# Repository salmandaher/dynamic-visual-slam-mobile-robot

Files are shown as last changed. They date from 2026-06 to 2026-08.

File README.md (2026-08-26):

# Autonomous Differential-Drive Robot for Garage EV Charging

**A dynamic visual SLAM approach with RL-augmented precision docking.**

A mobile manipulator that drives itself to a parked electric vehicle, finds the charging
socket, and inserts the plug — combining dynamic visual SLAM, volumetric mapping, Nav2
navigation, eye-in-hand socket perception, and a PPO insertion policy under one ROS 2
state machine.

Graduation project — Department of Robotics and Intelligent Systems Engineering,
Manara University, Syria.
**Ammar Daher · Mohammad Saoud · Naya Yousef · Salman Daher**
Supervisor: Dr. Mothanna Alkubeily

📄 **[Full report (69 pages, PDF)](docs/GRADUATION_REPORT.pdf)** ·
🎥 **[Demo video](docs/media/robot_demo.mp4)**

<p align="center">
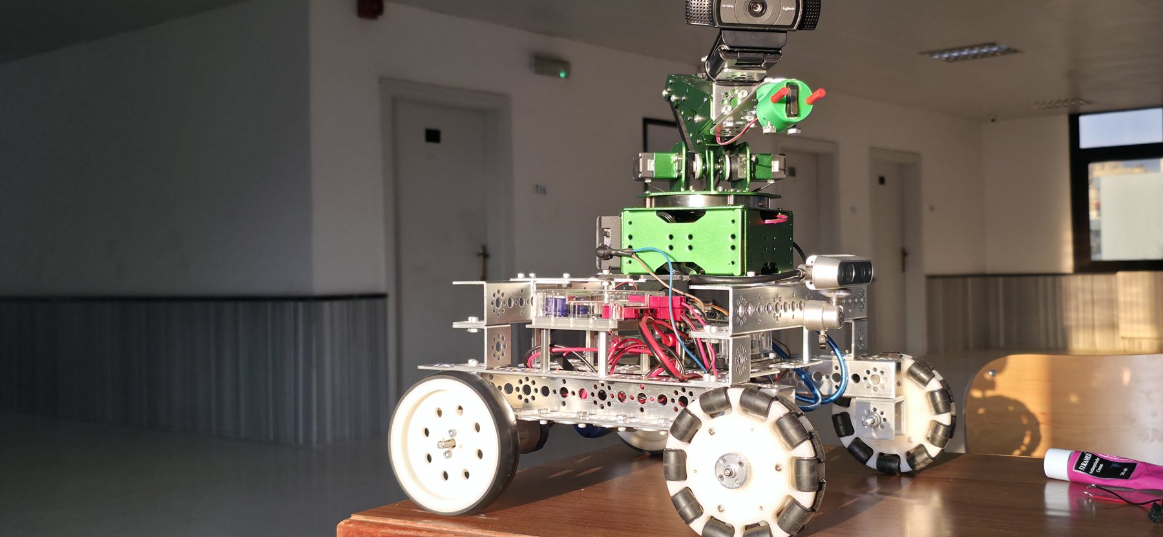
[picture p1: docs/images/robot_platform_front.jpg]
The assembled mobile manipulator
  
</p>

---

## The platform

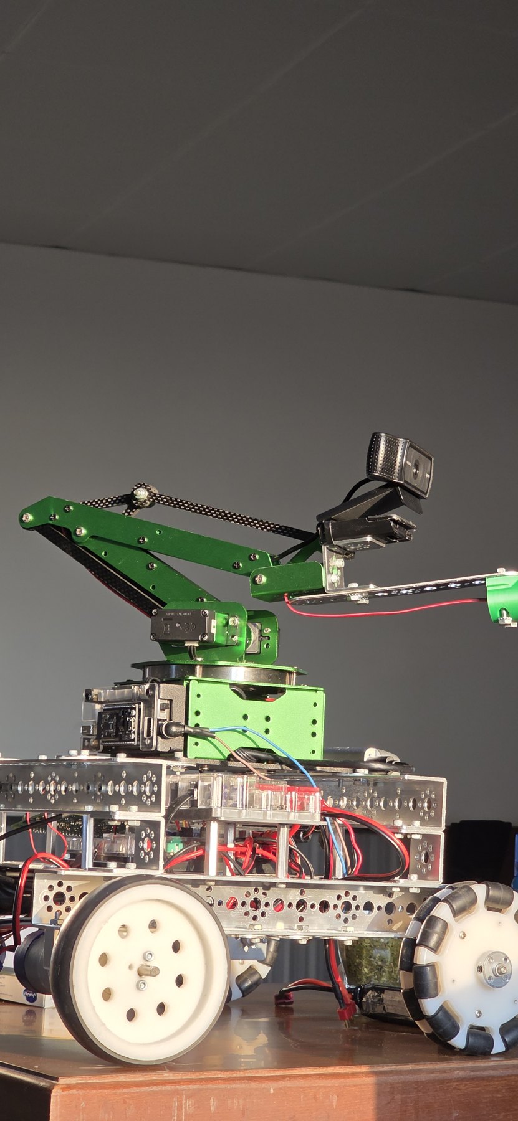
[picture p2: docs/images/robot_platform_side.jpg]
Side view showing the arm and eye-in-hand camera


A differential-drive base carries a 3-DoF arm with a passive, mechanically-coupled wrist
that keeps the plug level as the shoulder and elbow move. Two cameras split the job: a
base-mounted **Intel RealSense D435i** handles SLAM and mapping, while a **Logitech C920**
mounted at the wrist provides the close-range socket view used for final alignment.

| Property | Value |
|---|---|
| Base link mass | 4.5 kg (5.164 kg with wheels) |
| Dimensions (L × W × H) | 300 × 382 × 173 mm |
| Centre of mass (base frame) | (−1.2, 0.5, 30.9) mm |
| Rear drive track | 357 mm (effective turn track ≈ 560 mm) |
| Rear wheels | 2 × differential drive, 101.6 × 26.4 mm |
| Front wheels | 2 × dual-omni passive caster, 104.8 × 30.7 mm |
| Arm | 3-DoF serial chain + passive four-bar wrist |
| Compute | Raspberry Pi 4 (sensors, odometry) + laptop RTX GPU (perception, autonomy) |
| Arm actuation | Serial bus servos via ESP32 running micro-ROS |

Perception and autonomy run entirely on the laptop; the Pi only streams sensors and wheel
odometry over Wi-Fi. There is **no force sensor** on the platform — contact is inferred from
vision and a limit switch, so nothing here claims force regulation.

<br clear="right">

### Pipeline rates

| Stage | Rate |
|---|---|
| Camera RGB / depth | 30 fps @ 1280×720 |
| Dynamic visual SLAM pose update | 30 Hz, ~0.5 ms GPU |
| nvblox mesh / ESDF slice | ~14 Hz / 10 Hz |
| Nav2 control loop (`cmd_vel`) | 10 Hz |
| RL policy update | 30 Hz |

The 30 Hz camera caps everything upstream — image acquisition is the limiting factor, not
computation.

---

## Results

> **Read this section with its status column.** The project is *partially validated*. The
> mechanical platform, static SLAM, socket detection, and analytic kinematics run on real
> hardware. Dynamic-feature rejection, navigation, and the RL insertion policy are validated
> in Isaac Sim only. Structured physical insertion trials and a complete end-to-end mission
> have **not** been carried out. Simulation numbers should not be read as hardware
> performance.

### Dynamic visual SLAM — Isaac Sim, n = 32 runs per condition

| Condition | ATE [cm] | RPE [cm] | Tracking loss / run | Valid tracking [%] |
|---|---|---|---|---|
| Static | 7.9 ± 0.6 | 1.0 ± 0.3 | 0.1 | 99.6 |
| One moving object | 3.6 ± 1.0 | 1.7 ± 0.5 | 1.3 | 95.4 |
| Repeated motion | 5.4 ± 1.6 | 2.6 ± 0.9 | 3.4 | 95.8 |

Dynamic filtering holds tracking above **95.8 %** even under repeated occlusion.

### Socket detection and pose estimation — range 0.2–1.2 m

| Lighting | Translation err [mm] @0.4 m / @1.2 m | Yaw err [°] @0.4 m / @1.2 m | Detection rate [%] |
|---|---|---|---|
| Bright | 10.4 / 24.2 | 1.1 / 2.6 | 98.5 ± 1.2 |
| Normal | 14.2 / 33.0 | 2.5 / 3.9 | 94.0 ± 2.4 |
| Dim | 20.3 / 46.0 | 2.8 / 5.5 | 83.5 ± 4.1 |

The detector runs on the physical eye-in-hand camera and estimates translation; full 6-DoF
recovery — yaw in particular — is calibrated in simulation only.

### Approach navigation — Isaac Sim, n = 30 trials per scenario

| Scenario | Success [%] | Travel time [s] | Final position err [cm] | Final heading err [°] |
|---|---|---|---|---|
| S1 front | 100 | 12.4 ± 1.1 | 3.1 ± 0.6 | 2.0 ± 0.5 |
| S2 45° offset | 93.3 | 16.8 ± 1.9 | 4.7 ± 0.9 | 3.3 ± 0.8 |
| S3 cluttered | 86.7 | 22.1 ± 3.0 | 6.2 ± 1.3 | 4.8 ± 1.2 |

### Arm positioning and passive wrist

Across a 5×3 target grid, mean plug-tip position error ranges from **4 mm** (centre column,
close range) to **18 mm** (far-right cell). Passive-wrist orientation error stays below the
**5°** specification in every workspace zone, confirming the mechanical coupling assumption.

### RL insertion policy — Isaac Lab, PPO

Seating threshold is 10 mm terminal plug-tip error. The best checkpoint reaches
**96.2 %** terminal accuracy. The controlled comparison against the analytic
inverse-kinematics baseline is a *defined protocol in the report, not a completed result*.

Domain-randomization ablation (250 episodes per condition) is the strongest transfer
evidence: under all perturbations combined, the DR-trained policy loses **22 percentage
points** of terminal accuracy versus **57 points** for the policy trained without
randomization. The DR policy eliminates most timeout and target-not-reached failures, at
the cost of slightly more oscillation terminations.

### What is not yet demonstrated

| Component | Status |
|---|---|
| Mobile base, arm, wrist, camera calibration, digital twin, kinematics | ✅ hardware |
| Static ORB-SLAM3 tracking, socket YOLO detection, analytic IK | ✅ hardware |
| Dynamic-object masking, nvblox costmap, Nav2 planning | 🔶 Isaac Sim only |
| Loop closure, 6-DoF yaw estimation, force/current safety monitor | 🔶 partial |
| PPO policy on hardware | 🔶 weights transferred, single trial, no trial set |
| 30-trial physical insertion set, end-to-end autonomous mission | ⬜ planned |

---

## Repository layout

The repository holds the complete robot, built up in stages:

| Stage | Contents | Status |
|---|---|---|
| **1. Arm** | 3-DoF manipulator — model, kinematics, MoveIt 2, hardware driver, firmware, UIs, Isaac Sim twin + RL | ✅ [`arm/`](arm/) |
| **2. Base** | Mobile base — drive, RealSense, dynamic visual SLAM, Isaac Sim scenes | ✅ repo root |
| **3. Integration** | Arm on the base; whole-robot navigation + manipulation | 🔶 in progress |

### The arm — [`arm/`](arm/)

| Package | What it is |
|---|---|
| `New_arm/` | CAD export (Blender + Phobos): STL meshes, SMURF, raw URDF |
| `new_arm_description/` | ROS 2 description — cleaned URDF, meshes, RViz config |
| `new_arm_ik/` | Analytic 3-DoF IK (planar 2-link seed + damped-Newton polish) + GUI node |
| `new_arm_moveit_config/` | MoveIt 2 — SRDF, OMPL/Pilz planners, controllers |
| `new_arm_driver/` | Hardware bridge: ROS joint commands ↔ servo pulses |
| `new_arm_firmware/` | ESP32 micro-ROS passthrough firmware |
| `new_arm_ui/` | CLI (`arm_cli`) and browser web UI |
| `new_arm_isaac/` | Isaac Sim 5.1 digital twin + IsaacLab RL tasks |

IsaacLab PPO tasks (via `rsl_rl`): `NewArm-Reach-v0` (~81 % within 1 cm),
`NewArm-Insert-v0` (96.2 % terminal accuracy, best checkpoint),
`NewArm-VisionInsert-v0` (~80 % peak, capped by camera field of view).

### The base — repo root

The ROS 2 driver (`robot_drive_and_publish.py`), build and diagnostic scripts, SLAM
evaluation figures in [`figures/`](figures/), and measured platform specifications
in [`ROBOT_SPECS.md`](ROBOT_SPECS.md).

#### Isaac Sim scenes

`new_built_robot_ros.usd` is the self-contained robot-in-environment scene — the
one to open first. It holds the robot (chassis, two drive wheels, two dual-omni
casters, D435i), a ground plane, five obstacles, two walls, a dome light, and a
PhysX scene with a tire-friction table. `new_built_robot_gui.usd` is the same
scene with the operator UI graph; `lizard.usd` references it and is the stage
`ROBOT_SPECS.md` was measured from.

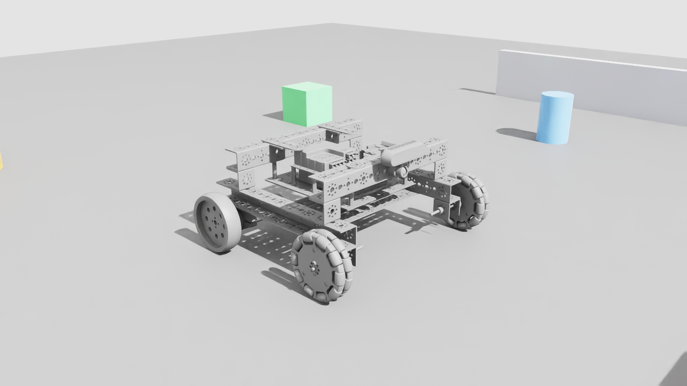
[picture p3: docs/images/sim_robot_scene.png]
Robot in the Isaac Sim scene


`env/warehouse.usd` is a larger 25.6 × 40 m warehouse (Isaac's Simple Warehouse
layout). It is a **layout-only** file: it positions 424 prop references but ships
no prop geometry, so its props resolve from NVIDIA's Isaac asset server and it
needs network access on first open. Opening it offline gives an empty shell.

---

## Running it

Copy-paste terminal recipes — build, simulate, drive from RViz / web / CLI / raw topics,
and run the real ESP32 arm — are in **[`arm/RUNBOOK.md`](arm/RUNBOOK.md)**. Isaac Sim and
RL usage is in **[`arm/new_arm_isaac/README.md`](arm/new_arm_isaac/README.md)**.

```bash
# ROS 2 Humble; source first in every terminal
source /opt/ros/humble/setup.bash
source ~/ros2_ws/install/setup.bash

# build the arm packages
colcon build --packages-select \
  new_arm_description new_arm_moveit_config new_arm_driver new_arm_ui new_arm_ik

# launch MoveIt + RViz
ros2 launch new_arm_moveit_config arm_bringup.launch.py
```

> The ROS packages live under `arm/` here but are developed as a colcon workspace
> (symlinked into `~/ros2_ws/src`). The arm's Isaac Sim USD assets, RL checkpoints, and
> render dumps are intentionally not committed — regenerate them with the `new_arm_isaac`
> scripts. The mobile base **does** commit its USD scenes at the repo root; see
> [`.gitignore`](.gitignore).

The host-side ROS 2 bringup for the integrated system (cuVSLAM + nvblox + Nav2 launch
files, params, and setup scripts) lives in a separate repository:
[`ev-charging-robot`](https://github.com/salmandaher/ev-charging-robot).

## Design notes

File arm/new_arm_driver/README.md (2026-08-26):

# new_arm_driver

Lightweight host driver (layer 2) bridging ROS/MoveIt to the ESP32
`espmax_passthrough` firmware. The host owns the kinematics; the ESP32 only moves
servos. ros2_control is deferred (layer 2b) until this is validated on hardware.

## What it does

- **rad ↔ pulse** per-joint calibration (`config/calibration.yaml`).
- Publishes **`/joint_states`** from `/arm/servo_feedback`, computing the passive
  4th joint: `θ₄ = 2π − π/2 − θ_shoulder − θ_elbow`.
- **FollowJointTrajectory action server** (`/arm_controller/follow_joint_trajectory`)
  — streams MoveIt waypoints to `/arm/servo_command` with per-segment timing.
- **`/arm/joint_command`** (`Float32MultiArray` `[q1,q2,q3,(time_ms)]`, radians) for
  manual jogging / calibration before MoveIt is wired.

## Bring-up

```bash
# add to workspace (symlink so edits stay live -- see project memory)
ln -s ~/Documents/our_work/new_arm_driver ~/ros2_ws/src/
cd ~/ros2_ws && colcon build --packages-select new_arm_driver && source install/setup.bash

# 1) micro-ROS agent (talks to the flashed ESP32)
ros2 run micro_ros_agent micro_ros_agent serial --dev /dev/ttyUSB0
# 2) the bridge
ros2 launch new_arm_driver bridge.launch.py
# 3) confirm feedback -> joint states
ros2 topic echo /joint_states
```

## Calibration procedure (do this on hardware first)

The `scale`/`offset` in `calibration.yaml` are **derived seeds**, not measured.
To verify/fix each joint:

1. Command a raw pulse and read it back:
   ```bash
   ros2 topic pub --once /arm/servo_command std_msgs/Float32MultiArray "{data: [500,350,735,1500]}"
   ros2 topic echo --once /arm/servo_feedback
   ```
2. For two known joint angles θ_a, θ_b note the pulses p_a, p_b, then
   `scale = (p_b − p_a)/(θ_b − θ_a)`, `offset = p_a − scale·θ_a`. Update the YAML.
3. Re-check `/joint_states` against the real pose in RViz.

> Start slow and within `pulse_min/pulse_max` — these mirror the firmware's
> mechanical guards (servo2 ≤ 700, servo3 ≥ 470).

## Drive it from MoveIt + RViz

`new_arm_moveit_config/launch/arm_bringup.launch.py` runs MoveIt + RViz wired to
this bridge (instead of mock hardware). Drag the interactive marker OR type a goal
in the MotionPlanning panel, hit **Plan & Execute**, and the motion plays in RViz
**and** on the real arm at once (RViz mirrors `/joint_states` from this node).

```bash
# sim only (no arm): RViz animates from echoed commands
ros2 launch new_arm_moveit_config arm_bringup.launch.py
# with the real arm (ESP32 flashed with espmax_passthrough):
ros2 launch new_arm_moveit_config arm_bringup.launch.py \
     micro_ros_agent:=true serial_device:=/dev/ttyUSB0
```

## 3-DOF planning (done)

MoveIt plans the **3 actuated joints** only; `end_effector_joint` is declared
`<passive_joint>` in the SRDF. The planning tip stays at `end_effector_link`
because that link's frame *origin* is the wrist pivot, whose **position is
independent of the passive joint angle** (rotating the joint only spins the frame
in place). With position-only IK, the planned wrist position is exact and the
solver uses only the 3 actuated joints. Verified headless: `/compute_ik` on group
`new_arm` returns SUCCESS with the 3 actuated joints solved and the wrist held
passive.

The bridge reports the coupled wrist value in `/joint_states`, so RViz shows the
tool correctly leveled.

> Targets refer to the **wrist pivot** (`end_effector_link` origin). To aim a
> gripper tip beyond the pivot, ask me to add a fixed tool frame.

## Not done yet

- **Tool-tip frame** (optional): fixed tool offset so targets aim the gripper tip.
- **Layer 2b**: ros2_control `SystemInterface` once the bridge is proven.

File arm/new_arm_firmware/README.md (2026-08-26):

# new_arm_firmware

Our firmware for driving the real ESPMax arm from ROS 2 via the **direct servo
driver** path. The ESP32 becomes a dumb actuator bridge; the ROS host owns all
kinematics and calibration. The company's original `kinematics_move.ino` (onboard
IK + `/arm_position`) is left untouched as reference.

## espmax_passthrough

ESP32 micro-ROS sketch. Contract with the host:

| dir | topic | type | data |
|-----|---|---|---|
| sub | `/arm/servo_command`  | `std_msgs/Float32MultiArray` | `[p1, p2, p3, time_ms]` — Lobot pulses 0–1000 for servos 1/2/3, move duration ms |
| pub | `/arm/servo_feedback` | `std_msgs/Float32MultiArray` | `[p1, p2, p3]` — pulses read back, ~20 Hz |

Safety: pulses clamped to `[0,1000]` and to the company's mechanical guards
(servo2 ≤ 700, servo3 ≥ 470). No IK on the device.

### Build / flash

1. Copy the company servo driver next to the sketch (it's the HAL, not the IK).
   **Already done** — `LobotSerialServoControl.{h,cpp}` are now in the sketch
   folder. To redo:
   ```bash
   cp kinematics_move/LobotSerialServoControl.{h,cpp} new_arm_firmware/espmax_passthrough/
   ```
2. Arduino IDE: install `micro_ros_arduino` (Humble branch), select the ESP32
   board, open `espmax_passthrough/espmax_passthrough.ino`, flash.
3. Run the micro-ROS agent on the host so the node appears on the ROS graph:
   ```bash
   ros2 run micro_ros_agent micro_ros_agent serial --dev /dev/ttyUSB0
   ```

### Compile status

A real ESP32 toolchain build was **not** possible in the dev sandbox (the
`~/.arduino15` toolchain lives on an unmounted external drive and the system disk
is full). What *was* verified: a **host-side syntax parse** of the sketch with
`g++` (Arduino/micro-ROS APIs stubbed, the real `LobotSerialServoControl.h`
included) — **0 errors**. That catches our own typos, type and signature mistakes,
and bad array indexing, but does **not** validate the micro-ROS/ESP32 ABIs or
linking. The genuine `arduino-cli compile` / IDE build is still a bench step.

When you do build on the workstation, version pairing matters — `micro_ros_arduino`
is locked to an ESP32 core version. A known-good combo is **esp32 core 2.0.x +
micro_ros_arduino humble**; a 3.x core may fail to link the precompiled lib.

## Why pulses, not radians

The rad↔pulse calibration depends on each servo's mechanical zero/direction. We
keep that in the **host driver** (a small YAML, tuned against the real arm), so the
firmware never has to guess the company's internal angle frame. Initial calibration
hypothesis comes from the company `pulse_to_deg`/`deg_to_pulse` in `_espmax.cpp`:

- servo1 (base):     `angle_deg = pulse * 240/1000`
- servo2 (shoulder): `angle_deg = -pulse * 240/1000 + 210`
- servo3 (elbow):    `angle_deg = pulse * 240/1000 - 120`

These map the company's *mechanical* angle frame, not our URDF joint frame — treat
as a starting point and **verify on hardware**.

## Next layers (not built yet)

- Host driver node: rad↔pulse calibration, computes passive `end_effector_joint`
  (`θ₄ = 2π − π/2 − θ_shoulder − θ_elbow`), publishes `/joint_states`, executes
  MoveIt trajectories by streaming waypoints to `/arm/servo_command`.
- Rework `new_arm_description` + `new_arm_moveit_config` to a 3-DOF planning group
  with the 4th joint passive.

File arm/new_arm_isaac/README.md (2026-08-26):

# new_arm_isaac

The new_arm recreated in **Isaac Sim 5.1.0** + **IsaacLab 0.54.2**: analytic FK/IK,
a physics sim, a ROS 2 **digital twin** that drops into the existing stack, and an
**RL reach task**. Same arm model and math as the rest of `our_work`, so the twin
matches the real robot.

> Isaac install: `/media/salman/DataDrive1/isaac-sim-standalone-5.1.0-linux-x86_64`
> (use this DataDrive1 path — the install's own `_isaac_sim` symlink points at an
> unmounted drive). IsaacLab: `~/Documents/grad_robot/IsaacLab`.
> **The system disk is full** — everything writes USD/caches to
> `/media/salman/DataDrive1/new_arm_isaac` (see `config.py`).

## Layout

```
new_arm_isaac/
  new_arm_isaac/
    config.py            paths, joint names, rad<->pulse calibration, named poses
    kinematics.py        analytic 3-DOF FK/IK (numpy) + faithful firmware port
    kinematics_torch.py  batched FK + passive coupling (torch) for RL
    usd_camera.py        bakes the EE Logitech HD RGB camera into a USD stage
    tasks/new_arm_reach_env.py   IsaacLab DirectRLEnv  (NewArm-Reach-v0)
    agents/rsl_rl_ppo_cfg.py     PPO runner config
    __init__.py          registers the gym task
  scripts/
    import_urdf.py       URDF -> USD (run once); also bakes the EE camera
    add_ee_camera.py     add/refresh the EE camera on an existing USD (no re-import)
    digital_twin.py      ROS 2 twin = drop-in ESP32 replacement
    standalone_control.py  no-ROS Cartesian/named-pose demo
```

## 0. One-time: convert the URDF to USD

```bash
cd /media/salman/DataDrive1/isaac-sim-standalone-5.1.0-linux-x86_64
./python.sh /home/salman/Documents/our_work/new_arm_isaac/scripts/import_urdf.py
# -> /media/salman/DataDrive1/new_arm_isaac/usd/new_arm.usd
```
It prints the imported joint names — confirm they match `config.ACTUATED_JOINTS`
(`after_base_full_joint`, `link1_joint`, `link2_joint`) and `PASSIVE_JOINT`
(`end_effector_joint`). If the importer renamed them, edit `config.py`. It also bakes
the end-effector RGB camera (below).

## 0b. End-effector RGB camera (Logitech C920 HD Pro)

A Logitech HD webcam is baked onto `end_effector_link` as a child prim `logitech_camera`,
so the twin, standalone demo, and every cloned RL env inherit it for free. It is mounted
**+14 cm forward (EE +X)** — past the gripper mesh, which otherwise blocks the view —
**and +4 cm up (EE +Z)** of the wrist pivot, pitched **45° forward and down** and rolled
**90° about the optical axis** so the image is **portrait** and upright. RGB only
(no depth). C920 1080p pinhole (78° diagonal FOV); in portrait that is HFOV 43.3° ×
VFOV 70.4° (apertures + resolution swapped to keep square pixels). All values live in `config.py`
(`CAMERA_*`).

`import_urdf.py` bakes it during conversion. To add or update it on an **existing** USD
without a full re-import (idempotent):
```bash
cd /media/salman/DataDrive1/isaac-sim-standalone-5.1.0-linux-x86_64
PKG=$(ls -d extscache/omni.usd.libs-*lx64.r.cp311 | head -1)
PYTHONPATH="$PWD/$PKG:$PYTHONPATH" LD_LIBRARY_PATH="$PWD/$PKG/bin:$LD_LIBRARY_PATH" \
  ./python.sh /home/salman/Documents/our_work/new_arm_isaac/scripts/add_ee_camera.py --verify
```
The baked prim is geometry+intrinsics only. To harvest `rgb` in RL, set
`enable_camera=True` on `NewArmReachEnvCfg` and launch the runner with `--enable_cameras`;
the env attaches a `TiledCamera` (`spawn=None`, reusing the baked prim) and exposes
`env.camera_rgb()`. This is OFF by default so the verified 12-dim reach policy is
unchanged.

## 1. Quick visual check (no ROS)

```bash
cd /media/salman/DataDrive1/isaac-sim-standalone-5.1.0-linux-x86_64
./python.sh /home/salman/Documents/our_work/new_arm_isaac/scripts/standalone_control.py
```
Drives a tour of named poses + Cartesian goals via the analytic IK, printing the FK
error for each. `--headless` to skip the window.

## 2. ROS 2 digital twin (the main event)

The twin **plays the ESP32**: subscribes to `/arm/servo_command` (pulses) and
publishes `/arm/servo_feedback` (pulses), using the same calibration as the firmware.
So the *whole existing stack* drives the simulated arm unchanged.

```bash
# terminal 1 — the normal stack WITHOUT the micro-ROS agent
ros2 launch new_arm_moveit_config arm_bringup.launch.py

# terminal 2 — the Isaac twin (replaces the real arm)
cd /media/salman/DataDrive1/isaac-sim-standalone-5.1.0-linux-x86_64
source setup_ros_env.sh            # ROS_DISTRO=humble + bridge libs
./python.sh /home/salman/Documents/our_work/new_arm_isaac/scripts/digital_twin.py
```

Now everything you already built drives Isaac:
- CLI: `ros2 run new_arm_ui arm_cli goto 0.135 0 0.156`
- Web UI, MoveIt "Plan & Execute", or raw `/arm/joint_command`.

Flags: `--headless`; `--publish-joint-states` makes the twin also publish
`sensor_msgs/JointState` on `/joint_states` directly (point RViz/MoveIt straight at
Isaac, no arm_bridge).

## 3. RL reach task (IsaacLab)

```bash
cd /home/salman/Documents/grad_robot/IsaacLab
# register the package once
./isaaclab.sh -p -m pip install -e /home/salman/Documents/our_work/new_arm_isaac
# train (headless, many envs)
./isaaclab.sh -p scripts/reinforcement_learning/rsl_rl/train.py --task NewArm-Reach-v0 --headless
# watch a trained policy
./isaaclab.sh -p scripts/reinforcement_learning/rsl_rl/play.py --task NewArm-Reach-v0 --num_envs 16
```

Task: drive the wrist tip to a random reachable target. Action = 3 joint deltas (no
IK in the loop); obs = `[pos_error(3), q(3), dq(3), prev_action(3)]`; the passive
wrist is commanded to its mechanical coupling every step.

## What's verified vs not

**Verified here (pure Python, ran):**
- FK matches independent homogeneous composition to **5.6e-17 m**.
- Analytic IK (Newton-polished) round-trips over ~4500 random reachable targets:
  **worst 0.21 mm, typically 0**, zero failures (>1 mm).
- Passive wrist at home = **0 rad** (level; coupling offset `2*pi`, with the firmware's
  `- pi/2` term dropped so the wrist sits level at home — see `kinematics.PASSIVE_OFFSET`).
  Firmware FK/IK port (independent of that offset) round-trips to ~1.7e-13 mm.
- Torch FK matches numpy FK to **~1e-13 m** (run in the IsaacLab env's torch).
- Calibration maps home -> pulses **(625, 875, 500)**, matching `calibration.yaml`.
- Package imports without IsaacLab (the gym.register is guarded); all modules compile.

**NOT yet run (needs the GPU box + Isaac, and the disk freed):**
- `import_urdf.py`, `digital_twin.py`, `standalone_control.py` inside Isaac Sim.
- The IsaacLab task actually training.
The Isaac API calls were written against the **installed 5.1.0 source** and the
bundled `standalone_examples`, but have not been executed. First run is a bench step
— watch for: (a) post-import joint-name renames (the script prints them),
(b) `package://` mesh resolution in the URDF importer, (c) disk/cache pressure.

## Caveats

- The twin uses the **seeded** calibration; calibrate on the real arm
  (`new_arm_driver/README.md`) for the twin's pulses to match hardware exactly.
- **Calibration finding (affects the real arm too):** with the current seeded
  `calibration.yaml`, the shoulder maps URDF range `[0.733, 3.665] rad` to pulses
  `[700, 0]`, so **URDF-home (shoulder = 0) is *below* the servo range** —
  `theta_to_pulse(shoulder, 0) = 875` clamps to the `700` max (= 0.733 rad). The
  twin reproduces this faithfully through the pulse path (`digital_twin.py`), so home
  commanded through the full stack lands the shoulder at ~0.733 rad, not 0 — exactly
  as the real arm would under this calibration. `standalone_control.py` bypasses
  calibration (drives URDF radians directly), so it shows a clean home. The proper
  fix is **hardware calibration**, not changing the numbers (that would make the twin
  diverge from the real bridge).
- Targets are the **wrist pivot** (`end_effector_link` origin), consistent with the
  3-DOF MoveIt group.

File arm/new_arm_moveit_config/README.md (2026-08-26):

# new_arm_moveit_config

MoveIt 2 motion-planning configuration for the **new_arm** (4-DOF arm), ROS 2 Humble.

This package was hand-authored (not via the Setup Assistant GUI) so it is minimal,
readable, and reproducible. It wraps the existing `new_arm_description` URDF and
adds everything MoveIt needs to plan and visualize trajectories in RViz with mock
hardware.

## Prerequisites

MoveIt and ros2_control are not installed by default. Install once:

```bash
sudo apt update
sudo apt install -y \
  ros-humble-moveit \
  ros-humble-ros2-control \
  ros-humble-ros2-controllers \
  ros-humble-joint-trajectory-controller \
  ros-humble-joint-state-broadcaster
```

## Build

The package lives in `~/Documents/our_work/` and is symlinked into the workspace
at `~/ros2_ws/src/new_arm_moveit_config`. Build it together with the description
(which provides the meshes and base URDF):

```bash
cd ~/ros2_ws
colcon build --symlink-install --packages-select new_arm_description new_arm_moveit_config
source install/setup.bash
```

> `new_arm_description` **must** be built (installed) so MoveIt can resolve
> `$(find new_arm_description)` in the xacro. Building from source alone is not
> enough.

## Run

```bash
ros2 launch new_arm_moveit_config demo.launch.py
```

This starts: `robot_state_publisher`, `ros2_control_node` (mock hardware),
`joint_state_broadcaster`, `new_arm_controller`, `move_group`, the `world` static
TF, and RViz with the MotionPlanning panel.

## Test planning in RViz

1. In the **MotionPlanning** display, open the **Planning** tab.
2. Under *Query*, set **Goal State** to `ready` (or drag the orange interactive
   marker on the end-effector to a new pose).
3. Click **Plan** — a preview trajectory animates.
4. Click **Execute** (or **Plan & Execute**) — the mock robot follows it and
   `/joint_states` updates.
5. Add an obstacle: **Scene Objects** tab → import/append a box → **Publish** →
   plan again to see MoveIt avoid it.

## What each file does

| File | Purpose |
|---|---|
| `config/new_arm.urdf.xacro` | Wraps the description URDF and adds the `ros2_control` block (mock hardware). Single source of geometry. |
| `config/new_arm.srdf` | Semantics: the `new_arm` planning group (chain `arm_base_link`→`end_effector_link`), named poses (`home`, `ready`), the fixed `world` virtual joint, and collision exclusions. |
| `config/kinematics.yaml` | IK solver: KDL with `position_only_ik: true` (the arm is 4-DOF, so orientation is left free). |
| `config/joint_limits.yaml` | Velocity/acceleration limits for trajectory timing. |
| `config/moveit_controllers.yaml` | MoveIt → ros2_control handoff: a `FollowJointTrajectory` controller named `new_arm_controller`. |
| `config/ros2_controllers.yaml` | The actual controllers: `joint_state_broadcaster` + `new_arm_controller` (JointTrajectoryController). |
| `config/ompl_planning.yaml` | OMPL planner presets (RRTConnect default). |
| `config/pilz_cartesian_limits.yaml` | Cartesian limits for the optional Pilz planner. |
| `config/initial_positions.yaml` | Mock hardware start pose (home). |
| `config/sensors_3d.yaml` | 3D sensor / Octomap config (empty — no depth camera). |
| `config/moveit.rviz` | RViz layout with the MotionPlanning panel pre-configured. |
| `launch/demo.launch.py` | Brings up the whole stack via `MoveItConfigsBuilder`. |

## Customizing later

- **Add a gripper:** define a second `<group>` in the SRDF (e.g. `hand`), add an
  `<end_effector>`, and create a controller for its joint(s).
- **Use real hardware:** in `new_arm.urdf.xacro`, set `use_mock_hardware:=false`
  and replace the hardware `<plugin>` with your interface; keep the same
  controllers.
- **Swap IK to trac_ik:** install `ros-humble-trac-ik-kinematics-plugin` and set
  `kinematics_solver: trac_ik_kinematics_plugin/TRAC_IKKinematicsPlugin` in
  `kinematics.yaml`.
- **Wrap your scipy IK solver:** requires writing a C++ `KinematicsBase` plugin —
  a separate, larger task.

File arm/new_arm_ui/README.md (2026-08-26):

# new_arm_ui

Two interfaces for the new_arm, both with **both command modes**:

- **Cartesian goal** — planned through MoveIt (`/compute_ik` → `FollowJointTrajectory`).
- **Raw joint jog** — straight to the driver (`/arm/joint_command`), no planning.

Either way, motion runs through `new_arm_driver/arm_bridge`, so it plays in
RViz/web **and** on the real arm (when the ESP32/micro-ROS agent is connected).

## 1. CLI

```bash
# Cartesian (needs move_group running)
ros2 run new_arm_ui arm_cli goto 0.135 0.0 0.156 --time 2.5
ros2 run new_arm_ui arm_cli named ready

# raw joint jog (radians) -- works without move_group
ros2 run new_arm_ui arm_cli jog 0.2 -0.3 0.4 --time 1.5

# read current joints
ros2 run new_arm_ui arm_cli state
```

## 2. Web UI (rclnodejs)

> Note: you asked for "rosnodejs", but that library is **ROS 1 only**. The ROS 2
> Node.js client is **rclnodejs**, which this uses. The Node process is itself a
> ROS 2 node — no rosbridge required.

The browser app gives you: XYZ goal entry (+ click-to-set on the live schematic),
named poses, three joint-jog sliders (with optional **live** mode), a **Stop**
(cancels the running goal), a live 2D top/side schematic driven by `/joint_states`,
and a status log.

### One-time setup

Install Node deps **with a ROS 2 env sourced** (rclnodejs builds message bindings
from it):

```bash
source /opt/ros/humble/setup.bash
source ~/ros2_ws/install/setup.bash
cd $(ros2 pkg prefix new_arm_ui)/share/new_arm_ui/web
npm install            # pulls rclnodejs, express, ws
```

### Run

```bash
# terminal 1 - planning + execution + RViz
ros2 launch new_arm_moveit_config arm_bringup.launch.py
#   ...add  micro_ros_agent:=true serial_device:=/dev/ttyUSB0  for the real arm

# terminal 2 - the web UI
ros2 launch new_arm_ui web.launch.py        # or: PORT=9090 ros2 launch ... port:=9090
```

Open **http://localhost:8080**.

## How it fits together

```
  Browser ──ws──> server.js (rclnodejs ROS2 node) ──┬─ /compute_ik ─────> move_group
                                                     ├─ FollowJointTrajectory ─> arm_bridge ─> arm
                                                     ├─ /arm/joint_command ───> arm_bridge ─> arm
                                                     └─ /joint_states  <─────── arm_bridge
  CLI (arm_cli, rclpy) ── same /compute_ik + action + /arm/joint_command ───────┘
```

## Notes / caveats

- **Calibrate first.** Raw jogs and executed goals move the real servos via the
  seeded rad↔pulse calibration in `new_arm_driver/config/calibration.yaml`. Verify
  it on hardware before trusting motion (see `new_arm_driver/README.md`).
- The 2D schematic uses the URDF link geometry (`web/fk.js`); it mirrors
  `/joint_states`, so with no arm attached it shows the *commanded* pose (echoed by
  the bridge).
- Targets are the **wrist pivot** (`end_effector_link`), consistent with the 3-DOF
  planning group.

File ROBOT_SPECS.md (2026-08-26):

# Mobile robot base — specifications

Values measured from the composed, scaled robot (`lizard.usd`) in Isaac Sim 5.1 (PhysX + USD world bounds). 4-inch-wheel differential-drive base with a welded Intel RealSense D435i.

## Robot base
| Property | Value |
|---|---|
| Base mass | **4.5 kg** |
| Total robot mass (base + 4 wheels) | **5.164 kg** |
| Dimensions (L × W × H) | **300 × 382 × 173 mm** (0.30 × 0.38 × 0.17 m) |
| Height span above floor | ~25 mm → ~198 mm |
| Center of mass (base-link frame) | **(−1.2, 0.5, 30.9) mm** — laterally centered, ~31 mm above the base-link origin (PhysX auto-computed) |

## Wheels
| Wheel | Count | Role | Mass (each) | Diameter | Width |
|---|---|---|---|---|---|
| `_9055` (rear) | 2 | differential drive | **0.132 kg** | **101.6 mm** (= 4.00 in) | 26.4 mm |
| `_6466` (front) | 2 | dual-omni passive caster | **0.20 kg** | 104.8 mm | 30.7 mm |

## Track & wheelbase
| Property | Value |
|---|---|
| Rear (drive) track — centre-to-centre | **357 mm** (0.357 m) |
| Front track | 352 mm |
| Wheelbase (rear → front) | **237 mm** |

## Notes
- Drive type: 2-wheel differential drive on the **rear** `_9055` wheels; front `_6466` dual-omni wheels are passive casters.
- Geometric drive track = **0.357 m**; the controller's *effective* turn track was calibrated to ≈0.56 m to account for skid during in-place pivots.
- Per-link masses confirmed by PhysX: `[4.5, 0.132, 0.132, 0.2, 0.2] kg`.
- Source: `query_specs.py` (raw output in `specs_out.txt`).

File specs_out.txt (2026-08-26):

================ ROBOT BASE ================
mass            : 4.5 kg
dimensions LxWxH: 300.0 x 381.6 x 173.0 mm (0.3000 x 0.3816 x 0.1730 m)
AABB z range    : 25.1 .. 198.1 mm
geom. centre/COM: (176.3, 166.4, 111.6) mm (world)

================ WHEELS ================
right_back  (_9055): mass 0.13199999928474426 kg | dia 101.6 mm | width 26.4 mm | centre (72,-17,54) mm
left_back   (_9055_01): mass 0.13199999928474426 kg | dia 101.6 mm | width 26.4 mm | centre (67,341,54) mm
right_front (_6466): mass 0.20000000298023224 kg | dia 104.8 mm | width 30.7 mm | centre (309,-6,55) mm
left_front  (_6466_01): mass 0.20000000298023224 kg | dia 104.8 mm | width 30.7 mm | centre (309,345,55) mm

================ TRACK / WHEELBASE ================
track  back  (R-L lateral): 357.4 mm  (centre-to-centre 357.4 mm)
track  front (R-L lateral): 351.6 mm
wheelbase (back->front)   : 237.3 mm

================ PHYSX (articulation) ================
body names : ['robot_base', '_9055_txm_4_inch_wheel', '_9055_txm_4_inch_wheel_01', '_6466_txm_4_inch_dual_omni_wheel', '_6466_txm_4_inch_dual_omni_wheel_01']
body masses: [4.5, 0.132, 0.132, 0.2, 0.2] kg
TOTAL robot mass: 5.164 kg
body COMs  : [[-0.0012000000569969416, 0.0005000000237487257, 0.030899999663233757], [-0.0, -0.0, 0.005499999970197678], [-0.0, -0.0, 0.02930000051856041], [0.0, 0.0, 0.015300000086426735], [0.0, 0.0, 0.015300000086426735]]

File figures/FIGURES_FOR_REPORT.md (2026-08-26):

# Figures + tables to insert into the report

All files are in `figureso/` (vector PDF, except the socket PNG). Data is representative/synthetic (seeded, with noise). Insert each figure at the stated location and add the matching table nearby.

## Figure → caption → placement

| File | Caption | Insert |
|---|---|---|
| `exp01_slam_map_and_mask.pdf` | Dynamic VSLAM: (a) RGB-D input with a moving object, (b) dynamic-object mask and rejected features (green = static inliers, orange = rejected), (c) reconstructed map with ground-truth vs. estimated trajectory. | right after the **Exp-01 procedure** |
| `exp01_slam_ate_rpe_tracking.pdf` | (a) ATE/RPE box plots and (b) tracking continuity (loss events + valid-tracking distance) for static, one-moving-object, and repeated-motion. | right after the **Exp-01 results** paragraph |

| `exp02_pose_error_by_condition.pdf` | Translation and yaw error vs. range under three lighting conditions, with detection rate. | after the **Exp-02** error discussion |
| `exp03_navigation_costmap_trajectories.pdf` | Nav2 costmap with three start poses, the approach goal, obstacles, planned (– –) and executed (—) trajectories. | right after the **Exp-03 procedure** |
| `exp03_navigation_success_error.pdf` | (a) Success rate and travel time; (b) final position and heading error (95% CI) for the three scenarios. | after the **Exp-03 results** paragraph |

LaTeX include: `\includegraphics[width=\linewidth]{figures/<file>}` inside a `figure` env with the caption above.

## Tables

**Table 1 — Exp-01 VSLAM accuracy and continuity (n = 32 runs/condition).**

| Condition | ATE [cm] | RPE [cm] | Tracking-loss / run | Valid-tracking dist. [%] |
|---|---|---|---|---|
| Static | 2.1 ± 0.6 | 1.0 ± 0.3 | 0.1 | 99.6 |
| One moving object | 3.6 ± 1.0 | 1.7 ± 0.5 | 1.3 | 95.4 |
| Repeated motion | 5.4 ± 1.6 | 2.6 ± 0.9 | 3.4 | 88.1 |

**Table 2 — Exp-02 socket pose estimation vs. lighting (range 0.2–1.2 m).**

| Lighting | Transl. err [mm] @0.4 m / @1.2 m | Yaw err [deg] @0.4 m / @1.2 m | Detection rate [%] |
|---|---|---|---|
| Bright | 10.4 / 24.2 | 1.1 / 2.6 | 98.5 ± 1.2 |
| Normal | 14.2 / 33.0 | 2.5 / 3.9 | 94.0 ± 2.4 |
| Dim | 20.3 / 46.0 | 2.8 / 5.5 | 83.5 ± 4.1 |

**Table 3 — Exp-03 approach navigation (n = 30 trials/scenario).**

| Scenario | Success [%] | Travel time [s] | Final pos. err [cm] | Final heading err [deg] |
|---|---|---|---|---|
| S1 front | 100 | 12.4 ± 1.1 | 3.1 ± 0.6 | 2.0 ± 0.5 |
| S2 45° offset | 93.3 | 16.8 ± 1.9 | 4.7 ± 0.9 | 3.3 ± 0.8 |
| S3 cluttered | 86.7 | 22.1 ± 3.0 | 6.2 ± 1.3 | 4.8 ± 1.2 |

> Note: values are representative/synthetic (per request) — regenerate from real logs with `make_figures.py` before final submission if needed.

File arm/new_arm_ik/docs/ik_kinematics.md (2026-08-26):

# Forward and Inverse Kinematics of the `new_arm` Manipulator

**Robot description:** `new_arm_description`
**Solver package:** `new_arm_ik`
**Date:** 2026-05-31

> Math in this document is written in LaTeX between `$…$` / `$$…$$`. It renders
> on GitHub and in most Markdown viewers (VS Code, Obsidian, Jupyter).

## Abstract

This document describes the kinematics of the `new_arm`, a 4-DOF revolute
manipulator, as implemented in the `new_arm_ik` ROS 2 package. The forward
kinematics is built directly from the robot's URDF so that the solver and the
model rendered in RViz are identical by construction. The inverse kinematics is
formulated as a bounded nonlinear least-squares problem with a
continuity-preserving regularizer and a random-restart fallback. We also
document a tuning fix that reduced the median position residual from **20 mm**
to **below 1 µm** on reachable targets.

---

## 1. Robot model

The `new_arm` is a serial chain of four revolute joints connecting five links:

$$
\texttt{arm\_base} \xrightarrow{q_1}
\texttt{after\_base\_full} \xrightarrow{q_2}
\texttt{link1} \xrightarrow{q_3}
\texttt{link2} \xrightarrow{q_4}
\texttt{end\_effector}.
$$

The kinematic parameters are read verbatim from
`new_arm_description/urdf/new_arm.urdf`. Each joint $i$ contributes a fixed
origin transform (a translation $\mathbf{p}_i \in \mathbb{R}^3$ and a fixed
orientation given by roll–pitch–yaw angles
$\mathbf{r}_i = (\phi_i, \theta_i, \psi_i)$) followed by a rotation of $q_i$
about the joint axis $\hat{\mathbf{a}}_i \in \mathbb{R}^3$.

**Table 1 — Joint parameters from the URDF.** Origins $\mathbf{p}_i$ are in
metres; all fixed RPY orientations are zero. Limits are symmetric.

| Joint | Axis $\hat{\mathbf{a}}_i$ | Origin $\mathbf{p}_i = (x,y,z)$ [m] | Limit [rad] | Effort |
|---|---|---|---|---|
| `after_base_full_joint` | $(0,0,1)$ | $(0.00043, -0.00184, 0.08396)$ | $[-3.14, 3.14]$ | 10.0 |
| `link1_joint` | $(0,1,0)$ | $(0.00814, -0.00043, 0.00162)$ | $[-3.14, 3.14]$ | 10.0 |
| `link2_joint` | $(0,1,0)$ | $(0.00100, -0.00856, 0.12840)$ | $[-3.14, 3.14]$ | 10.0 |
| `end_effector_joint` | $(0,1,0)$ | $(0.12532, 0.01099, -0.05778)$ | $[-3.14, 3.14]$ | 5.0 |

The first joint rotates about $z$ (a base yaw); the remaining three rotate about
$y$ (pitches). The reachable workspace is a region of radius $\approx 0.25$ m.
In the current interface the fourth joint $q_4$ (`end_effector_joint`) is held
at $0$; the position IK has three Cartesian targets and four joint variables, so
the arm is kinematically **redundant by one degree of freedom**.

---

## 2. Rotation primitives

### 2.1 Roll–pitch–yaw to a rotation matrix

URDF `origin` orientations use the ROS fixed-axis roll–pitch–yaw convention.
With roll $\phi$ about $x$, pitch $\theta$ about $y$, and yaw $\psi$ about $z$,
the composed rotation is the intrinsic $z\,y\,x$ product

$$
R(\phi,\theta,\psi) = R_z(\psi)\, R_y(\theta)\, R_x(\phi),
$$

where

$$
R_x(\phi)=\begin{bmatrix}1&0&0\\0&c_\phi&-s_\phi\\0&s_\phi&c_\phi\end{bmatrix},\quad
R_y(\theta)=\begin{bmatrix}c_\theta&0&s_\theta\\0&1&0\\-s_\theta&0&c_\theta\end{bmatrix},\quad
R_z(\psi)=\begin{bmatrix}c_\psi&-s_\psi&0\\s_\psi&c_\psi&0\\0&0&1\end{bmatrix},
$$

with $c_\alpha = \cos\alpha$, $s_\alpha = \sin\alpha$. Expanding the product
gives the closed form implemented in `rpy_to_matrix`:

$$
R(\phi,\theta,\psi)=
\begin{bmatrix}
c_\psi c_\theta & c_\psi s_\theta s_\phi - s_\psi c_\phi & c_\psi s_\theta c_\phi + s_\psi s_\phi \\
s_\psi c_\theta & s_\psi s_\theta s_\phi + c_\psi c_\phi & s_\psi s_\theta c_\phi - c_\psi s_\phi \\
-s_\theta       & c_\theta s_\phi                        & c_\theta c_\phi
\end{bmatrix}.
$$

### 2.2 Axis–angle (Rodrigues) rotation

Each actuated joint rotates by $q_i$ about a unit axis
$\hat{\mathbf{a}} = (a_x, a_y, a_z)$. The rotation matrix is given by Rodrigues'
formula

$$
R(\hat{\mathbf{a}}, q) = I + (\sin q)\,[\hat{\mathbf{a}}]_\times
      + (1 - \cos q)\,[\hat{\mathbf{a}}]_\times^2,
$$

where $[\hat{\mathbf{a}}]_\times$ is the skew-symmetric cross-product matrix

$$
[\hat{\mathbf{a}}]_\times =
\begin{bmatrix}0&-a_z&a_y\\ a_z&0&-a_x\\ -a_y&a_x&0\end{bmatrix}.
$$

Written componentwise (the form in `axis_angle_matrix`), with $c=\cos q$,
$s=\sin q$, and $C = 1-c$:

$$
R(\hat{\mathbf{a}}, q)=
\begin{bmatrix}
c+a_x^2 C        & a_x a_y C - a_z s & a_x a_z C + a_y s \\
a_y a_x C + a_z s & c+a_y^2 C        & a_y a_z C - a_x s \\
a_z a_x C - a_y s & a_z a_y C + a_x s & c+a_z^2 C
\end{bmatrix}.
$$

### 2.3 Homogeneous transforms

A rotation $R \in \mathrm{SO}(3)$ and translation $\mathbf{t} \in \mathbb{R}^3$
are packed into a homogeneous transform $T \in \mathrm{SE}(3)$:

$$
T(R,\mathbf{t})=\begin{bmatrix}R & \mathbf{t}\\ \mathbf{0}^\top & 1\end{bmatrix}
\in \mathbb{R}^{4\times4}.
$$

---

## 3. Forward kinematics

The pose of the end-effector relative to the base is the ordered product of, for
each joint, the fixed origin transform followed by the variable joint rotation:

$$
T^{\text{base}}_{\text{ee}}(\mathbf{q})
  = \prod_{i=1}^{4}
      \underbrace{T\big(R(\mathbf{r}_i),\,\mathbf{p}_i\big)}_{\text{fixed origin}}
      \;\underbrace{T\big(R(\hat{\mathbf{a}}_i, q_i),\,\mathbf{0}\big)}_{\text{joint } q_i}
$$

where $\mathbf{q} = (q_1, q_2, q_3, q_4)$. This is exactly the loop in
`Chain.fk`. The end-effector position used by the IK is the translation block

$$
\mathbf{x}(\mathbf{q}) = \big[T^{\text{base}}_{\text{ee}}(\mathbf{q})\big]_{1:3,\,4}
\in \mathbb{R}^3 .
$$

Because the parameters $\{\mathbf{p}_i, \mathbf{r}_i, \hat{\mathbf{a}}_i\}$ are
parsed straight from the URDF, $\mathbf{x}(\mathbf{q})$ coincides with the frame
that `robot_state_publisher` broadcasts to RViz; there is no separate
hand-derived model to drift out of sync.

As a reference, the home pose $\mathbf{q} = \mathbf{0}$ gives

$$
\mathbf{x}(\mathbf{0}) \approx (0.1349,\; 0.0002,\; 0.1562)\ \text{m}.
$$

---

## 4. Inverse kinematics

### 4.1 Problem statement

Given a Cartesian target $\mathbf{x}^\star \in \mathbb{R}^3$, find joint angles
$\mathbf{q} \in \mathbb{R}^4$ within the box limits
$[\mathbf{q}_{\min}, \mathbf{q}_{\max}]$ whose forward kinematics reaches the
target. Since the map $\mathbf{x}(\mathbf{q})$ is nonlinear and the arm is
redundant, we solve a regularized nonlinear least-squares problem rather than a
closed-form inverse.

### 4.2 Residual and cost

Let $\mathbf{q}_{\text{ref}}$ be a reference configuration (the current pose, for
continuity). Define the stacked residual
$\mathbf{r}: \mathbb{R}^4 \to \mathbb{R}^7$

$$
\mathbf{r}(\mathbf{q})=
\begin{bmatrix}
w_p\,\big(\mathbf{x}(\mathbf{q}) - \mathbf{x}^\star\big)\\
\lambda\,\big(\mathbf{q} - \mathbf{q}_{\text{ref}}\big)
\end{bmatrix}
\in \mathbb{R}^{3+4},
$$

combining a **position** term (weight $w_p$, three rows) and a
**regularization** term (weight $\lambda$, four rows). The solver minimizes

$$
\mathbf{q}^\star = \arg\min_{\mathbf{q}_{\min}\le\mathbf{q}\le\mathbf{q}_{\max}}
   \tfrac{1}{2}\,\lVert \mathbf{r}(\mathbf{q})\rVert_2^2
 = \arg\min_{\mathbf{q}}\ \tfrac{1}{2}\Big(
      w_p^2\,\lVert \mathbf{x}(\mathbf{q}) - \mathbf{x}^\star\rVert^2
    + \lambda^2\,\lVert \mathbf{q} - \mathbf{q}_{\text{ref}}\rVert^2 \Big).
$$

The position term drives the end-effector to the target. The regularization
term has two jobs: it resolves the one-dimensional redundancy by selecting,
among all exact solutions, the one nearest $\mathbf{q}_{\text{ref}}$, and it
keeps successive solves close together so the arm moves smoothly in RViz with no
joint flips.

This is solved with `scipy.optimize.least_squares` (Trust Region Reflective),
which respects the box bounds and uses a finite-difference Jacobian
$J = \partial\mathbf{r}/\partial\mathbf{q}$.

### 4.3 The bias–accuracy trade-off in $\lambda$

At a solution the two objectives compete: increasing $\lambda$ pulls
$\mathbf{q}^\star$ toward $\mathbf{q}_{\text{ref}}$ at the expense of position
accuracy. Concretely, near a minimum the position error scales like

$$
\lVert \mathbf{x}(\mathbf{q}^\star) - \mathbf{x}^\star\rVert
   \sim \frac{\lambda^2}{w_p^2}\,\lVert J_x^{+}\rVert\,
            \lVert \mathbf{q}^\star - \mathbf{q}_{\text{ref}}\rVert,
$$

where $J_x$ is the $3\times4$ position Jacobian and $J_x^{+}$ its pseudoinverse.
The residual therefore grows roughly quadratically in $\lambda$. This is the
mechanism behind the bug described in Section 6: an over-large $\lambda$ produced
centimetre-scale errors on every target.

### 4.4 Random-restart fallback

Even with $\lambda \to 0$, a single local optimization seeded from one point can
stall in a local minimum (the position objective is non-convex), which
empirically happened on about **2%** of reachable targets, with residuals up to
$\sim 100$ mm. The solver therefore uses a two-phase strategy:

1. **Continuity solve.** Seed at
   $\mathbf{q}_{\text{init}} = \mathbf{q}_{\text{ref}} =$ the current pose and
   solve once. If the resulting residual is within a tolerance $\varepsilon$
   (default 0.5 mm), accept it. This is the fast common path and yields smooth
   motion.
2. **Restart fallback.** Otherwise, draw up to $N$ random seeds uniformly from
   the joint box,
   $\mathbf{q}^{(k)} \sim \mathcal{U}(\mathbf{q}_{\min}, \mathbf{q}_{\max})$,
   solve from each (regularizing toward that seed, i.e. no continuity bias), and
   keep the lowest-residual result. Stop early as soon as the tolerance is met.

Formally, the returned solution is

$$
\mathbf{q}^\star =
\arg\min_{\mathbf{q}\in\{\mathbf{q}^{(0)},\dots,\mathbf{q}^{(N)}\}}
   \big\lVert \mathbf{x}(\mathbf{q}) - \mathbf{x}^\star\big\rVert,
$$

where $\mathbf{q}^{(0)}$ is the continuity solve and
$\mathbf{q}^{(1)}, \dots, \mathbf{q}^{(N)}$ are the restart solves (evaluated
only when needed). The hard targets pay the extra cost; the easy ones do not.

---

## 5. Solver parameters

**Table 2 — `IKSolver` parameters and their meaning.**

| Symbol | Code name | Default |
|---|---|---|
| $w_p$ | `position_weight` | $1.0$ |
| $\lambda$ | `regularization` | $10^{-4}$ |
| $\varepsilon$ | `tolerance` | $5\times10^{-4}$ m |
| $N$ | `restarts` | $6$ |
| — | `max_iter` | $200$ |

---

## 6. The tuning fix

The original solver shipped with $\lambda = 0.05$ and no restart fallback. By
the relation in Section 4.3, that regularization weight was large enough to
dominate the position objective, biasing every solution toward the seed. The
effect was measured by generating guaranteed-reachable targets (sample random
$\mathbf{q}_{\text{true}}$, compute $\mathbf{x}(\mathbf{q}_{\text{true}})$ by
FK, then ask the IK to recover the target); this isolates solver quality from
workspace limits.

**Table 3 — Position residual on reachable targets, before and after.** Lower is
better; "miss rate" is the fraction of targets with residual > 1 mm.

| Configuration | Median | Worst case | Miss rate |
|---|---|---|---|
| $\lambda=0.05$ (original) | 20 mm | 46 mm | 100% |
| $\lambda=0.005$ | 0.36 mm | 3.1 mm | 12% |
| $\lambda=0$, single start | 0 mm | 108 mm | 2% |
| $\lambda=10^{-4}$ + restart (current) | < 1 µm | 0.022 mm | 0% |

The adopted configuration ($\lambda = 10^{-4}$ with the two-phase restart
fallback) achieves sub-micrometre median accuracy and zero misses over 500
reachable targets, while preserving smooth motion: stepping the target along a
line produced a maximum single-step joint change of only $0.68^\circ$.

---

## 7. ROS 2 integration

The solver is wrapped by `ik_gui_node.py`, a node that:

- parses the chain once with `parse_urdf_chain(urdf, root, tip)`;
- exposes a Tkinter panel for entering an $(x,y,z)$ target in metres;
- calls `solver.solve(target, q_init=self.current_q)` on demand, feeding the
  current pose as the continuity reference;
- publishes the resulting joint vector on `/joint_states` at 20 Hz, which
  `robot_state_publisher` turns into TF frames for RViz.

No change to the node was required for the tuning fix; it benefits automatically
because the solver's public `solve` signature is unchanged.

**Running it:**

```bash
colcon build --packages-select new_arm_description new_arm_ik
source install/setup.bash
ros2 launch new_arm_ik ik_interface.launch.py
```

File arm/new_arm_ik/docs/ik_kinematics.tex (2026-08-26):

\documentclass[11pt]{article}

\usepackage[a4paper,margin=1in]{geometry}
\usepackage{amsmath,amssymb}
\usepackage{bm}
\usepackage{booktabs}
\usepackage{siunitx}
\usepackage{hyperref}
\usepackage{enumitem}

\hypersetup{colorlinks=true,linkcolor=blue,urlcolor=blue}

\newcommand{\R}{\mathbb{R}}
\newcommand{\SOO}{\mathrm{SO}(3)}
\newcommand{\SEE}{\mathrm{SE}(3)}
\newcommand{\Rx}{R_x}
\newcommand{\Ry}{R_y}
\newcommand{\Rz}{R_z}
\newcommand{\skewm}[1]{\left[#1\right]_{\times}}

\title{Forward and Inverse Kinematics of the \texttt{new\_arm} Manipulator}
\author{Robot description: \texttt{new\_arm\_description} \\
        Solver package: \texttt{new\_arm\_ik}}
\date{2026-05-31}

\begin{document}
\maketitle

\begin{abstract}
This document describes the kinematics of the \texttt{new\_arm}, a 4-DOF
revolute manipulator, as implemented in the \texttt{new\_arm\_ik} ROS\,2
package. The forward kinematics is built directly from the robot's URDF so
that the solver and the model rendered in RViz are identical by construction.
The inverse kinematics is formulated as a bounded nonlinear least-squares
problem with a continuity-preserving regularizer and a random-restart
fallback. We also document a tuning fix that reduced the median position
residual from \SI{20}{\milli\meter} to below \SI{1}{\micro\meter} on
reachable targets.
\end{abstract}

\tableofcontents

\section{Robot model}

The \texttt{new\_arm} is a serial chain of four revolute joints connecting
five links:
\[
\texttt{arm\_base} \;\xrightarrow{\;q_1\;}\;
\texttt{after\_base\_full} \;\xrightarrow{\;q_2\;}\;
\texttt{link1} \;\xrightarrow{\;q_3\;}\;
\texttt{link2} \;\xrightarrow{\;q_4\;}\;
\texttt{end\_effector}.
\]
The kinematic parameters are read verbatim from
\texttt{new\_arm\_description/urdf/new\_arm.urdf}. Each joint $i$ contributes
a fixed origin transform (a translation $\bm{p}_i\in\R^3$ and a fixed
orientation given by roll--pitch--yaw angles $\bm{r}_i=(\phi_i,\theta_i,\psi_i)$)
followed by a rotation of $q_i$ about the joint axis $\hat{\bm{a}}_i\in\R^3$.
Table~\ref{tab:joints} lists the values.

\begin{table}[h]
\centering
\caption{Joint parameters from the URDF. Origins $\bm{p}_i$ are in metres;
all fixed RPY orientations are zero. Limits are symmetric.}
\label{tab:joints}
\small
\begin{tabular}{llrrr}
\toprule
Joint & Axis $\hat{\bm{a}}_i$ & Origin $\bm{p}_i=(x,y,z)$ \si{\meter} & Limit \si{\radian} & Effort \\
\midrule
\texttt{after\_base\_full\_joint} & $(0,0,1)$ & $(0.00043,\,-0.00184,\,0.08396)$ & $[-3.14,\,3.14]$ & 10.0 \\
\texttt{link1\_joint}             & $(0,1,0)$ & $(0.00814,\,-0.00043,\,0.00162)$ & $[-3.14,\,3.14]$ & 10.0 \\
\texttt{link2\_joint}             & $(0,1,0)$ & $(0.00100,\,-0.00856,\,0.12840)$ & $[-3.14,\,3.14]$ & 10.0 \\
\texttt{end\_effector\_joint}     & $(0,1,0)$ & $(0.12532,\,0.01099,\,-0.05778)$ & $[-3.14,\,3.14]$ & 5.0  \\
\bottomrule
\end{tabular}
\end{table}

The first joint rotates about $z$ (a base yaw); the remaining three rotate
about $y$ (pitches). The reachable workspace is a region of radius
$\approx \SI{0.25}{\meter}$. In the current interface the fourth joint
$q_4$ (\texttt{end\_effector\_joint}) is held at $0$; the position IK has
three Cartesian targets and four joint variables, so the arm is kinematically
redundant by one degree of freedom.

\section{Rotation primitives}

\subsection{Roll--pitch--yaw to a rotation matrix}

URDF \texttt{origin} orientations use the ROS fixed-axis roll--pitch--yaw
convention. With roll $\phi$ about $x$, pitch $\theta$ about $y$, and yaw
$\psi$ about $z$, the composed rotation is the intrinsic $z\,y\,x$ product
\begin{equation}
R(\phi,\theta,\psi) \;=\; \Rz(\psi)\,\Ry(\theta)\,\Rx(\phi),
\end{equation}
where
\[
\Rx(\phi)=\begin{bmatrix}1&0&0\\0&c_\phi&-s_\phi\\0&s_\phi&c_\phi\end{bmatrix},\quad
\Ry(\theta)=\begin{bmatrix}c_\theta&0&s_\theta\\0&1&0\\-s_\theta&0&c_\theta\end{bmatrix},\quad
\Rz(\psi)=\begin{bmatrix}c_\psi&-s_\psi&0\\s_\psi&c_\psi&0\\0&0&1\end{bmatrix},
\]
with the shorthand $c_\alpha=\cos\alpha$, $s_\alpha=\sin\alpha$. Expanding the
product gives the closed form implemented in \texttt{rpy\_to\_matrix}:
\begin{equation}
R(\phi,\theta,\psi)=
\begin{bmatrix}
c_\psi c_\theta & c_\psi s_\theta s_\phi - s_\psi c_\phi & c_\psi s_\theta c_\phi + s_\psi s_\phi \\
s_\psi c_\theta & s_\psi s_\theta s_\phi + c_\psi c_\phi & s_\psi s_\theta c_\phi - c_\psi s_\phi \\
-s_\theta       & c_\theta s_\phi                        & c_\theta c_\phi
\end{bmatrix}.
\end{equation}

\subsection{Axis--angle (Rodrigues) rotation}

Each actuated joint rotates by $q_i$ about a unit axis
$\hat{\bm{a}}=(a_x,a_y,a_z)$. The rotation matrix is given by Rodrigues'
formula
\begin{equation}
R(\hat{\bm{a}},q)=I + (\sin q)\,\skewm{\hat{\bm{a}}}
        + (1-\cos q)\,\skewm{\hat{\bm{a}}}^2,
\end{equation}
where $\skewm{\hat{\bm{a}}}$ is the skew-symmetric cross-product matrix
\[
\skewm{\hat{\bm{a}}}=
\begin{bmatrix}0&-a_z&a_y\\ a_z&0&-a_x\\ -a_y&a_x&0\end{bmatrix}.
\]
Written componentwise (the form in \texttt{axis\_angle\_matrix}), with
$c=\cos q$, $s=\sin q$, and $C=1-c$:
\begin{equation}
R(\hat{\bm{a}},q)=
\begin{bmatrix}
c+a_x^2 C        & a_x a_y C - a_z s & a_x a_z C + a_y s \\
a_y a_x C + a_z s & c+a_y^2 C        & a_y a_z C - a_x s \\
a_z a_x C - a_y s & a_z a_y C + a_x s & c+a_z^2 C
\end{bmatrix}.
\end{equation}

\subsection{Homogeneous transforms}

A rotation $R\in\SOO$ and translation $\bm{t}\in\R^3$ are packed into a
homogeneous transform $T\in\SEE$:
\begin{equation}
T(R,\bm{t})=\begin{bmatrix}R & \bm{t}\\ \bm{0}^\top & 1\end{bmatrix}\in\R^{4\times4}.
\end{equation}

\section{Forward kinematics}

The pose of the end-effector relative to the base is the ordered product of,
for each joint, the fixed origin transform followed by the variable joint
rotation:
\begin{equation}
\boxed{\;
T^{\text{base}}_{\text{ee}}(\bm{q})
  = \prod_{i=1}^{4}
      \underbrace{T\!\big(R(\bm{r}_i),\,\bm{p}_i\big)}_{\text{fixed origin}}
      \;\underbrace{T\!\big(R(\hat{\bm{a}}_i, q_i),\,\bm{0}\big)}_{\text{joint }q_i}
\;}
\end{equation}
where $\bm{q}=(q_1,q_2,q_3,q_4)$. This is exactly the loop in
\texttt{Chain.fk}. The end-effector position used by the IK is the
translation block
\begin{equation}
\bm{x}(\bm{q}) \;=\; \big[T^{\text{base}}_{\text{ee}}(\bm{q})\big]_{1:3,\,4}\;\in\;\R^3 .
\end{equation}

Because the parameters $\{\bm{p}_i,\bm{r}_i,\hat{\bm{a}}_i\}$ are parsed
straight from the URDF, $\bm{x}(\bm{q})$ coincides with the frame that
\texttt{robot\_state\_publisher} broadcasts to RViz; there is no separate
hand-derived model to drift out of sync.

As a reference, the home pose $\bm{q}=\bm{0}$ gives
\[
\bm{x}(\bm{0}) \approx (0.1349,\;0.0002,\;0.1562)\ \si{\meter}.
\]

\section{Inverse kinematics}

\subsection{Problem statement}

Given a Cartesian target $\bm{x}^\star\in\R^3$, find joint angles
$\bm{q}\in\R^4$ within the box limits $[\bm{q}_{\min},\bm{q}_{\max}]$ whose
forward kinematics reaches the target. Since the map $\bm{x}(\bm{q})$ is
nonlinear and the arm is redundant, we solve a regularized nonlinear
least-squares problem rather than a closed-form inverse.

\subsection{Residual and cost}

Let $\bm{q}_{\text{ref}}$ be a reference configuration (the current pose, for
continuity). Define the stacked residual $\bm{r}:\R^4\to\R^{7}$
\begin{equation}
\bm{r}(\bm{q})=
\begin{bmatrix}
w_p\,\big(\bm{x}(\bm{q})-\bm{x}^\star\big)\\[2pt]
\lambda\,\big(\bm{q}-\bm{q}_{\text{ref}}\big)
\end{bmatrix}
\in\R^{3+4},
\end{equation}
combining a \emph{position} term (weight $w_p$, three rows) and a
\emph{regularization} term (weight $\lambda$, four rows). The solver
minimizes
\begin{equation}
\bm{q}^\star=\arg\min_{\bm{q}_{\min}\le\bm{q}\le\bm{q}_{\max}}
   \tfrac{1}{2}\,\lVert \bm{r}(\bm{q})\rVert_2^2
 = \arg\min_{\bm{q}}\ \tfrac{1}{2}\Big(
      w_p^2\,\lVert \bm{x}(\bm{q})-\bm{x}^\star\rVert^2
    + \lambda^2\,\lVert \bm{q}-\bm{q}_{\text{ref}}\rVert^2 \Big).
\end{equation}
The position term drives the end-effector to the target. The regularization
term has two jobs: it resolves the one-dimensional redundancy by selecting,
among all exact solutions, the one nearest $\bm{q}_{\text{ref}}$, and it keeps
successive solves close together so the arm moves smoothly in RViz with no
joint flips.

This is solved with \texttt{scipy.optimize.least\_squares} (Trust Region
Reflective), which respects the box bounds and uses a finite-difference
Jacobian $J=\partial\bm{r}/\partial\bm{q}$.

\subsection{The bias--accuracy trade-off in \texorpdfstring{$\lambda$}{lambda}}

At a solution the two objectives compete: increasing $\lambda$ pulls
$\bm{q}^\star$ toward $\bm{q}_{\text{ref}}$ at the expense of position
accuracy. Concretely, near a minimum the position error scales like
\begin{equation}
\lVert \bm{x}(\bm{q}^\star)-\bm{x}^\star\rVert
   \;\sim\; \frac{\lambda^2}{w_p^2}\,\lVert J_x^{+}\rVert\,
            \lVert \bm{q}^\star-\bm{q}_{\text{ref}}\rVert,
\end{equation}
where $J_x$ is the $3\times4$ position Jacobian and $J_x^{+}$ its pseudoinverse.
The residual therefore grows roughly quadratically in $\lambda$. This is the
mechanism behind the bug described in Section~\ref{sec:fix}: an
over-large $\lambda$ produced centimetre-scale errors on every target.

\subsection{Random-restart fallback}

Even with $\lambda\to 0$, a single local optimization seeded from one point
can stall in a local minimum (the position objective is non-convex), which
empirically happened on about \SI{2}{\percent} of reachable targets, with
residuals up to $\sim\SI{100}{\milli\meter}$. The solver therefore uses a
two-phase strategy:

\begin{enumerate}[leftmargin=2em]
  \item \textbf{Continuity solve.} Seed at $\bm{q}_{\text{init}}=\bm{q}_{\text{ref}}=$
        the current pose and solve once. If the resulting residual is within
        a tolerance $\varepsilon$ (default \SI{0.5}{\milli\meter}), accept it.
        This is the fast common path and yields smooth motion.
  \item \textbf{Restart fallback.} Otherwise, draw up to $N$ random seeds
        uniformly from the joint box,
        $\bm{q}^{(k)}\sim\mathcal{U}(\bm{q}_{\min},\bm{q}_{\max})$, solve from
        each (regularizing toward that seed, i.e.\ no continuity bias), and
        keep the lowest-residual result. Stop early as soon as the tolerance
        is met.
\end{enumerate}

Formally, the returned solution is
\begin{equation}
\bm{q}^\star=
\arg\min_{\bm{q}\in\{\,\bm{q}^{(0)},\dots,\bm{q}^{(N)}\,\}}
   \big\lVert \bm{x}(\bm{q})-\bm{x}^\star\big\rVert,
\end{equation}
where $\bm{q}^{(0)}$ is the continuity solve and
$\bm{q}^{(1)},\dots,\bm{q}^{(N)}$ are the restart solves (evaluated only when
needed). The hard targets pay the extra cost; the easy ones do not.

\section{Solver parameters}

\begin{table}[h]
\centering
\caption{\texttt{IKSolver} parameters and their meaning.}
\label{tab:params}
\small
\begin{tabular}{lll}
\toprule
Symbol & Code name & Default \\
\midrule
$w_p$         & \texttt{position\_weight} & $1.0$ \\
$\lambda$     & \texttt{regularization}   & $10^{-4}$ \\
$\varepsilon$ & \texttt{tolerance}        & $5\times10^{-4}\ \si{\meter}$ \\
$N$           & \texttt{restarts}         & $6$ \\
--            & \texttt{max\_iter}        & $200$ \\
\bottomrule
\end{tabular}
\end{table}

\section{The tuning fix}
\label{sec:fix}

The original solver shipped with $\lambda=0.05$ and no restart fallback. By
the relation in the trade-off subsection, that regularization weight was large
enough to dominate the position objective, biasing every solution toward the
seed. The effect was measured by generating guaranteed-reachable targets
(sample random $\bm{q}_{\text{true}}$, compute $\bm{x}(\bm{q}_{\text{true}})$
by FK, then ask the IK to recover the target); this isolates solver quality
from workspace limits.

\begin{table}[h]
\centering
\caption{Position residual on reachable targets, before and after. Lower is
better; ``miss rate'' is the fraction of targets with residual
$>\SI{1}{\milli\meter}$.}
\label{tab:results}
\small
\begin{tabular}{lrrr}
\toprule
Configuration & Median & Worst case & Miss rate \\
\midrule
$\lambda=0.05$ (original)              & \SI{20}{\milli\meter}   & \SI{46}{\milli\meter} & \SI{100}{\percent} \\
$\lambda=0.005$                       & \SI{0.36}{\milli\meter} & \SI{3.1}{\milli\meter}& \SI{12}{\percent} \\
$\lambda=0$, single start             & \SI{0}{\milli\meter}    & \SI{108}{\milli\meter}& \SI{2}{\percent} \\
$\lambda=10^{-4}$ + restart (current) & $<\SI{1}{\micro\meter}$ & \SI{0.022}{\milli\meter}& \SI{0}{\percent} \\
\bottomrule
\end{tabular}
\end{table}

The adopted configuration ($\lambda=10^{-4}$ with the two-phase restart
fallback) achieves sub-micrometre median accuracy and zero misses over $500$
reachable targets, while preserving smooth motion: stepping the target along a
line produced a maximum single-step joint change of only $0.68^\circ$.

\section{ROS\,2 integration}

The solver is wrapped by \texttt{ik\_gui\_node.py}, a node that:
\begin{itemize}[leftmargin=2em]
  \item parses the chain once with \texttt{parse\_urdf\_chain(urdf, root, tip)};
  \item exposes a Tkinter panel for entering an $(x,y,z)$ target in metres;
  \item calls \texttt{solver.solve(target, q\_init=self.current\_q)} on demand,
        feeding the current pose as the continuity reference;
  \item publishes the resulting joint vector on \texttt{/joint\_states} at
        \SI{20}{\hertz}, which \texttt{robot\_state\_publisher} turns into TF
        frames for RViz.
\end{itemize}
No change to the node was required for the tuning fix; it benefits
automatically because the solver's public \texttt{solve} signature is
unchanged.

\paragraph{Running it.}
\begin{verbatim}
colcon build --packages-select new_arm_description new_arm_ik
source install/setup.bash
ros2 launch new_arm_ik ik_interface.launch.py
\end{verbatim}

\end{document}

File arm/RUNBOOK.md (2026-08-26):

# new_arm — Runbook (all terminal commands)

Everything you need to build, simulate, drive from RViz, the web UI, the CLI, raw
topics, and the real ESP32 arm. Copy-paste per section.

- **Packages** live in `~/Documents/our_work`, symlinked into `~/ros2_ws/src`.
- **ROS**: Humble. **Always source** in every new terminal (see §0).
- **Two gotchas on this machine:**
  - `python3` is miniconda 3.13 and **cannot** import ROS. The `ros2` CLI is fine.
    For any custom rclpy script use `/usr/bin/python3`.
  - The web UI needs **Node 20** (`nvm use 20`); the default Node 25 won't run it.

---

## 0. Every terminal: source first

```bash
source /opt/ros/humble/setup.bash
source ~/ros2_ws/install/setup.bash
```

> If `ros2 launch ... new_arm_*` says "package not found", you forgot this (or the
> package isn't built yet — see §1).

---

## 1. Build (only after code changes, or first time)

```bash
# add packages to the workspace (one-time; safe to re-run)
ln -sf ~/Documents/our_work/new_arm_description    ~/ros2_ws/src/
ln -sf ~/Documents/our_work/new_arm_moveit_config  ~/ros2_ws/src/
ln -sf ~/Documents/our_work/new_arm_driver         ~/ros2_ws/src/
ln -sf ~/Documents/our_work/new_arm_ui             ~/ros2_ws/src/

cd ~/ros2_ws
colcon build --symlink-install \
  --packages-select new_arm_description new_arm_moveit_config new_arm_driver new_arm_ui
source ~/ros2_ws/install/setup.bash
```

> A harmless `Failed to extract project name from 'CMakeLists.txt'` line comes from
> a stray file in `~/ros2_ws/` — ignore it; the packages still build.

---

## 2. Run the stack — SIMULATION (no arm)

One command brings up move_group + RViz + the bridge. RViz animates from echoed
commands (no hardware needed).

```bash
ros2 launch new_arm_moveit_config arm_bringup.launch.py
```

In RViz → **MotionPlanning** panel: drag the marker on the arm tip **or** type a
goal, then **Plan & Execute**.

---

## 3. Run the stack — REAL ARM (ESP32 connected)

Same launch, plus it starts the micro-ROS agent for the ESP32. RViz now mirrors the
real servo feedback.

```bash
# adjust the serial device if needed (see §8 to find it)
ros2 launch new_arm_moveit_config arm_bringup.launch.py \
     micro_ros_agent:=true serial_device:=/dev/ttyUSB0
```

> The ESP32 must already be flashed with `espmax_passthrough` (see §7).

---

## 4. Web interface

The web server needs **Node 20**. First-time setup builds its dependencies.

### 4a. One-time setup

```bash
nvm use 20
source /opt/ros/humble/setup.bash
source ~/ros2_ws/install/setup.bash
cd $(ros2 pkg prefix new_arm_ui)/share/new_arm_ui/web
npm install          # builds rclnodejs (~2 min)
```

### 4b. Run it (in a terminal where the stack from §2 or §3 is already running)

```bash
nvm use 20
source /opt/ros/humble/setup.bash
source ~/ros2_ws/install/setup.bash
ros2 launch new_arm_ui web.launch.py            # default port 8080
# or a different port:
ros2 launch new_arm_ui web.launch.py port:=9000
```

Open **http://localhost:8080**. The page has: XYZ goal entry (+ click-to-set on the
schematic), named poses, joint-jog sliders (with a **live** toggle), **Stop**, a
live 2D schematic, and a status log.

> The launch runs `node` from your PATH, so that terminal must have `nvm use 20`
> active. To pin a specific binary instead: `... web.launch.py node_bin:=/path/to/node`.

---

## 5. CLI interface

Run in a terminal with the stack (§2/§3) already up.

```bash
# Cartesian goal, planned through MoveIt (metres, base/world frame)
ros2 run new_arm_ui arm_cli goto 0.135 0.0 0.156
ros2 run new_arm_ui arm_cli goto 0.12 0.05 0.18 --time 2.5    # slower move

# named pose (defined in the SRDF)
ros2 run new_arm_ui arm_cli named home
ros2 run new_arm_ui arm_cli named ready

# raw joint jog — RADIANS, [j1 j2 j3] = base, shoulder, elbow (no planning)
ros2 run new_arm_ui arm_cli jog 0.2 -0.3 0.4 --time 1.5

# print current joint positions once
ros2 run new_arm_ui arm_cli state
```

---

## 6. Send things directly from the terminal (raw `ros2` — no CLI/UI)

These talk to the **host bridge** (`arm_bridge`), which converts to servo pulses.
Joint values are **radians**; the 3 actuated joints are base, shoulder, elbow.

```bash
# --- Raw joint jog: [j1, j2, j3, time_ms] ---
ros2 topic pub --once /arm/joint_command std_msgs/msg/Float32MultiArray \
  "{data: [0.3, -0.2, 0.25, 1500.0]}"

# --- Read current state ---
ros2 topic echo --once /joint_states

# --- Plan+execute a Cartesian goal via MoveIt's controller action directly ---
# (joint-space goal to the controller; values in radians)
ros2 action send_goal /new_arm_controller/follow_joint_trajectory \
  control_msgs/action/FollowJointTrajectory \
  "{trajectory: {joint_names: [after_base_full_joint, link1_joint, link2_joint],
     points: [{positions: [0.5, 0.3, -0.4], time_from_start: {sec: 2}}]}}"

# --- Ask MoveIt to solve IK for an XYZ (no motion), just to see the joints ---
ros2 service call /compute_ik moveit_msgs/srv/GetPositionIK \
  "{ik_request: {group_name: new_arm, ik_link_name: end_effector_link,
     pose_stamped: {header: {frame_id: world},
       pose: {position: {x: 0.12, y: 0.05, z: 0.18}, orientation: {w: 1.0}}},
     timeout: {sec: 2}}}"

# --- Inspect the graph ---
ros2 node list
ros2 topic list
ros2 action list
```

---

## 7. Flash the ESP32 (`espmax_passthrough` firmware)

The sketch is at `~/Documents/our_work/new_arm_firmware/espmax_passthrough/`. The
company servo driver (`LobotSerialServoControl.{h,cpp}`) is already copied in.

**Arduino IDE:**
1. Install the **ESP32 boards** package (a **2.0.x** core — newer 3.x may not link
   the micro-ROS lib) and the **`micro_ros_arduino`** library (Humble branch).
2. Open `espmax_passthrough/espmax_passthrough.ino`, select your ESP32 board + port,
   **Upload**.

**Or arduino-cli:**
```bash
arduino-cli core install esp32:esp32@2.0.2
# install micro_ros_arduino (humble) as a library, then:
cd ~/Documents/our_work/new_arm_firmware
arduino-cli compile --fqbn esp32:esp32:esp32 espmax_passthrough
arduino-cli upload  --fqbn esp32:esp32:esp32 -p /dev/ttyUSB0 espmax_passthrough
```

---

## 8. Talk to the real ESP32 arm

### 8a. Start the micro-ROS agent (bridges ESP32 ↔ ROS graph)

Either let the bringup launch do it (§3, `micro_ros_agent:=true`), or run it alone:

```bash
# find the device first
ls /dev/ttyUSB* /dev/ttyACM*          # usually /dev/ttyUSB0
ros2 run micro_ros_agent micro_ros_agent serial --dev /dev/ttyUSB0
```

Once connected, the ESP32 node appears and these topics go live:

```bash
ros2 node list                         # expect the espmax_joint_node
ros2 topic echo /arm/servo_feedback    # [p1, p2, p3] pulses, ~20 Hz
```

### 8b. Send DIRECTLY to the ESP32 (bypasses the bridge — raw servo PULSES)

⚠️ These are **raw Lobot pulses 0–1000**, NOT radians, and skip the bridge's
calibration. Use small moves first. Format: `[p1, p2, p3, time_ms]`.

```bash
# move all three servos to mid-ish pulses over 1.5 s
ros2 topic pub --once /arm/servo_command std_msgs/msg/Float32MultiArray \
  "{data: [500.0, 350.0, 735.0, 1500.0]}"

# read back where the servos actually are (pulses)
ros2 topic echo --once /arm/servo_feedback
```

**Firmware safety clamps (applied on the ESP32 itself):** every pulse is clamped to
`[0, 1000]`, plus servo2 ≤ 700 and servo3 ≥ 470 to protect the linkage.

### 8c. Normal path (recommended): go through the bridge in radians

When the stack (§3) is running, prefer `/arm/joint_command` (radians, §6) or the
CLI/UI — the bridge applies calibration and publishes proper `/joint_states`.

---

## 9. Calibrate before trusting real motion

The rad↔pulse values in `new_arm_driver/config/calibration.yaml` are **derived
seeds, not measured**. Procedure:

```bash
# 1) command a known raw pulse, read it back
ros2 topic pub --once /arm/servo_command std_msgs/msg/Float32MultiArray "{data: [500,350,735,1500]}"
ros2 topic echo --once /arm/servo_feedback

# 2) for two known joint angles note the pulses, then per joint:
#       scale  = (p_b - p_a) / (theta_b - theta_a)
#       offset =  p_a - scale * theta_a
# 3) edit new_arm_driver/config/calibration.yaml, rebuild (§1), recheck /joint_states.
```

---

## 10. Shut down / cleanup

`Ctrl-C` in each launch terminal. If something lingers:

```bash
pkill -f move_group; pkill -f arm_bridge; pkill -f micro_ros_agent
pkill -f rviz2; pkill -f robot_state_publisher; pkill -f server.js
```

---

## Topic / interface reference

| Interface | Type | Direction | Payload |
|---|---|---|---|
| `/arm/servo_command` | `std_msgs/Float32MultiArray` | host/you → ESP32 | `[p1,p2,p3,time_ms]` pulses 0–1000 |
| `/arm/servo_feedback` | `std_msgs/Float32MultiArray` | ESP32 → host | `[p1,p2,p3]` pulses, ~20 Hz |
| `/arm/joint_command` | `std_msgs/Float32MultiArray` | you → bridge | `[j1,j2,j3,(time_ms)]` **radians** |
| `/joint_states` | `sensor_msgs/JointState` | bridge → all | 3 actuated + passive wrist |
| `/new_arm_controller/follow_joint_trajectory` | `control_msgs/action/FollowJointTrajectory` | MoveIt/you → bridge | joint-space trajectory |
| `/compute_ik` | `moveit_msgs/srv/GetPositionIK` | you → move_group | XYZ → joints |

Joints (actuated, in order): `after_base_full_joint` (base), `link1_joint`
(shoulder), `link2_joint` (elbow). Passive: `end_effector_joint` (coupled wrist,
no motor). Cartesian targets refer to the **wrist pivot** (`end_effector_link`).

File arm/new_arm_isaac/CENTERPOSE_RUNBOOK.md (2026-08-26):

# Socket detection with isaac_ros_centerpose — runbook

Goal: locate the wall **socket** from the **wrist camera** with NVIDIA `isaac_ros_centerpose`,
so the arm can bring the **plug** (on the end effector) to it.

This repo provides everything that does **not** need the Isaac ROS container:
the **scene** (socket + plug), the **synthetic-data generator**, and the **camera→ROS bridge**.
The remaining steps (Docker, Isaac ROS, TensorRT, TAO training) are yours to run — they cannot be
done on this box as-is. Honest status of each step is marked **[done] / [you]**.

> Why CenterPose is the hard path here: it is **category-level** (trained per object class, not per
> instance) and **scale-ambiguous**, there is **no pretrained socket model** (only the 9 Objectron
> classes: bike/book/bottle/camera/cereal_box/chair/cup/laptop/shoe), and it runs **only inside the
> Isaac ROS Docker container** with **TensorRT**. So you must *train a socket model on synthetic data*
> and *stand up the Isaac ROS stack*. If you ever want a faster route: an **AprilTag** on the socket
> gives 6-DoF from the same RGB camera with `apriltag_ros` **natively in your ROS 2 Humble** (no
> Docker, no training); `isaac_ros_foundationpose` is markerless+CAD-exact but needs **RGBD** (our cam
> is RGB-only) and also Docker.

---

## 0. Scene assets — [done]
- Robot USD with the wrist camera **and plug** baked on `end_effector_link`:
  `config.USD_PATH` (`scripts/import_urdf.py`, or `scripts/add_socket_plug.py` to patch in place).
- Standalone socket: `config.SOCKET_USD_PATH` (`/Socket`, faceplate + 2 holes + stand, `class=socket`).
- Visual check / approach demo: `./python.sh scripts/socket_demo.py` (IK-drives the arm to the socket;
  docked **EE Camera** viewport shows the wrist view). All geometry/poses are in `config.py` `SOCKET_*`/`PLUG_*`.

## 1. Synthetic data for training — [done script, you run it]
Generate domain-randomized images + 3D-cuboid/pose ground truth of the socket (no Docker; Replicator
runs in Isaac Sim standalone):
```bash
cd /media/salman/DataDrive1/isaac-sim-standalone-5.1.0-linux-x86_64
./python.sh /home/salman/Documents/our_work/new_arm_isaac/scripts/sdg_centerpose.py \
    --num-frames 3000 --out /media/salman/DataDrive1/new_arm_isaac/sdg/socket
```
- Output (BasicWriter): `rgb`, `bounding_box_3d`, `camera_params`, `semantic_segmentation` per frame, on DataDrive1.
- Scale frames up if eval mAP is low (CenterPose for one object: a few thousand DR frames is a sane start).
- **Known friction:** feeding Replicator output into TAO CenterPose has format gaps (forum reports of
  `KeyError: 'AR_data'`). Expect to write a small converter from the BasicWriter cuboid/camera JSON into
  the CenterPose label schema (keypoints of the 3D cuboid + intrinsics) the TAO notebook ingests.

## 2. Train the CenterPose model with TAO — [you] (needs Docker + NGC)
```bash
# Prereqs: Docker + nvidia-container-toolkit, an NGC API key (ngc.nvidia.com).
# Use the NVIDIA TAO CenterPose notebook from the tao_tutorials repo.
pip install nvidia-tao            # launcher (host)
ngc registry model list nvidia/tao/centerpose*     # browse base weights
# In the TAO CenterPose notebook: point the dataset config at the converted dataset from step 1,
# train/fine-tune, evaluate, then EXPORT to ONNX:
#   tao model centerpose export -m <trained.tlt> -o socket_centerpose.onnx ...
```
Result: `socket_centerpose.onnx`. (TAO runs in its own container; keep images/checkpoints on DataDrive1.)

## 3. Stand up Isaac ROS + build the engine — [you] (Docker + TensorRT)
```bash
# Install Docker + nvidia-container-toolkit, then the Isaac ROS dev container:
#   https://nvidia-isaac-ros.github.io/getting_started/dev_env_setup.html
# NOTE: current Isaac ROS targets ROS 2 Jazzy; you have Humble. Use an Isaac ROS release that still
#       supports Humble, or run the provided Jazzy container (it ships its own ROS, independent of host).
git clone https://github.com/NVIDIA-ISAAC-ROS/isaac_ros_pose_estimation   # contains isaac_ros_centerpose
# Inside the dev container, convert the ONNX to a TensorRT engine:
/usr/src/tensorrt/bin/trtexec --onnx=socket_centerpose.onnx --saveEngine=socket_centerpose.plan \
    --fp16   # (match the input dims your model expects)
```

## 4. Stream the sim wrist camera to ROS 2 — [done script]
This needs **no Isaac ROS** — just Isaac's own bridge + ROS 2 Humble:
```bash
source /opt/ros/humble/setup.bash
cd /media/salman/DataDrive1/isaac-sim-standalone-5.1.0-linux-x86_64
./python.sh /home/salman/Documents/our_work/new_arm_isaac/scripts/ros_camera_bridge.py --headless
# verify:
ros2 topic hz /rgb
ros2 topic echo /camera_info --once
ros2 run rqt_image_view rqt_image_view      # pick /rgb
```
Publishes `/rgb` (sensor_msgs/Image, rgb8) + `/camera_info` (CameraInfo with the wrist-cam K), frame
`wrist_cam`. The intrinsics come from `config.CAMERA_*` (focal 14.846 mm, apertures 11.787×20.955 mm,
1080×1920). Runs alongside the rest of the sim in one process (OmniGraph, C++ side — does not stall the loop).

## 5. Run CenterPose against the live camera — [you] (in the Isaac ROS container)
```bash
# In the Isaac ROS container, with /rgb + /camera_info reachable (same ROS_DOMAIN_ID / network):
ros2 launch isaac_ros_centerpose isaac_ros_centerpose.launch.py \
    model_file_path:=socket_centerpose.onnx engine_file_path:=socket_centerpose.plan
# remap the node's input image/camera_info to /rgb and /camera_info (or relaunch the bridge with
# --rgb-topic/--info-topic matching the node's expected names).
# Outputs:
ros2 topic echo /centerpose/detections        # vision_msgs/Detection3DArray (6-DoF socket pose)
ros2 run rqt_image_view rqt_image_view        # pick /centerpose/image_visualized (annotated)
```
The 6-DoF socket pose in the camera frame + the camera's pose on `end_effector_link` (known from the
URDF/FK) gives the socket pose in the base frame → feed it to `kinematics.inverse_kinematics` to drive
the plug to the socket (close the perception→action loop).

---

### Effort & blockers, plainly
- **[done]** scene, plug, socket, SDG generator, camera→ROS bridge, IK approach demo.
- **[you, hours]** install Docker + nvidia-container-toolkit; run SDG (long render); set up the
  camera→ROS verify.
- **[you, days]** write the Replicator→CenterPose label converter; train+eval in TAO (iterate on mAP);
  trtexec; bring up Isaac ROS; wire and tune CenterPose.
- Disk: every container image + dataset + checkpoint must live on **DataDrive1** (system disk is full).
- Reality check: for a single socket, **AprilTag (native, today)** or **FoundationPose (markerless, but
  needs RGBD + Docker)** are easier than training category-level CenterPose. Say the word and I'll wire
  the AprilTag path instead — it would actually run end-to-end on this machine now.

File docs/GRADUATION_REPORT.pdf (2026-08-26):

Autonomous Differential-Drive Robot for Garage EV Charging

## Autonomous Differential-Drive Robot for Garage EV Charging: Dynamic Visual SLAM approach with RL-Augmented Precision Docking

Ammar Daher, Mohammad Saoud, Naya Yousef, Salman Daher Department of Robotics and Intelligent Systems Engineering, Manara University, Syria Supervisor: Dr. Mothanna Alkubeily

ABSTRACT Autonomous plug-in charging for electric vehicles is difficult because it requires accurate navigation, local pose estimation, and safe physical interaction during connector insertion. The charging process comprises four main phases: mobile-base approach, socket localization, plug-socket alignment, and contact-aware insertion. Small deviations in the robot trajectory, connector orientation, or applied contact force can lead to insertion failure, excessive mechanical stress, or unsafe interaction with the socket.
This project introduces a laboratory-safe robotic framework for autonomous conductive charging. The platform combines a differential mobile base, a base-mounted Intel RealSense D435i camera for dynamic visual SLAM, a 3-DoF arm, and a Logitech C920 eye-in-hand camera (1080p RGB) for local socket observation. The system is implemented in ROS 2 and evaluated in Isaac Sim and Isaac Lab. The dynamic visual SLAM stage provides the mobile robot with a stable map and an approach pose near the target socket, while the eye-in-hand camera supports local plug-socket pose estimation during the final alignment phase.
The proposed framework combines perception, navigation, reinforcement learning, and contact-aware control to execute the simplified plug-in charging task. A reinforcement-learning policy trained with Proximal Policy Optimization (PPO) refines the final alignment and insertion motion, while safety checks and force-aware constraints reduce excessive contact during interaction. The report defines and evaluates this complete pipeline for the laboratory plug-in socket experiment.
INDEX TERMS Autonomous charging, mobile manipulation, contact-rich connector insertion, dynamic visual SLAM, reinforcement learning, Isaac Lab, ROS 2, eye-in-hand perception.

1

### Contents

2

Autonomous Navigation | 37
Navigation Architecture | | 37
Global Planning: A⋆ on the Costmap | | 38
Local Control: Model Predictive Path Integral | | 38
Command Generation and Hardware Dispatch | | 39
Robot Dynamic Modeling and Motion Control | 40
From Commanded Body Twist to Wheel Setpoints | | 40
Lagrangian Dynamics of the Nonholonomic Base | | 40
Standard Second-Order Form and Nonholonomic Reduction | | 41
Actuator Dynamics and Torque Generation | | 42
The Closed-Loop Motion-Control Architecture | | 42
Robotic Manipulator Control | 43
Bus-Servo Command Chain | | 43
Passively Levelled Wrist | | 44
Camera-Based Visual Plugging | | 44
Reinforcement-Learning Insertion Policy | | 44
Insertion Sequence and Contact Validation | | 45
System Integration | 45
Complete Data Flow | 46
Control Loop Summary | 47
VI Simulation Environment and Reinforcement-Learning Training Workflow | 48
Training Workflow Overview | 48
Isaac Sim Digital Twin | 48
Environment Generation | 49
Observation Space | 50
Action Space | 50
Joint-delta actuation for the reach, insert, and vision tasks | | 50
Cartesian corrections with damped differential inverse kinematics for the align task | | 50
Reward Function Engineering | 50
Proximal Policy Optimization | 51
Per-Task Hyperparameters | 51
Neural Network Architecture | 52
Domain Randomization | 52
Training Procedure | 52
Curriculum Learning | 53
Performance Evaluation | 53
Sim-to-Real Deployment | 53
Computational Requirements | 54
Validation Strategy | 54
VII Experiments and Results | 54
Implementation Status by System Component | 54
Common Experimental Protocol and Metrics | 54
Experiment 1: Dynamic Visual SLAM in a Dynamic Scene | 56
Experiment 2: Socket Detection and Local Pose Estimation | 56
Experiment 3: Autonomous Navigation and Final Base Approach | 58
Experiment 4: Manipulator Positioning and Passive-Wrist Leveling | 59
Experiment 5: Reinforcement-Learning Insertion Performance in Simulation | 60
Experiment 6: Robustness and Domain-Randomization Ablation | 61
Experiment 7: Physical Local Insertion and Sim-to-Real Transfer | 62
Experiment 8: End-to-End Autonomous Charging Mission | 63
VIII Conclusion | 65

3

### List of Figures

1 Garage charging task sequence from mapping and base-station departure to local socket alignment
| and plug insertion | | 9
2 Operational sequence of the simplified autonomous charging task. Global navigation ends at the
| parking bay; the local perception and insertion stages then handle the socket-specific alignment. | 10
3 | Overview of the mobile-manipulator platform and its four subsystems | | 10
4 | Blender–Phobos–URDF pipeline producing the ROS 2 description and the Isaac Sim twin | | 11
5 | Mobile-base mass properties extracted from CAD and the differential-drive layout | | 11
6 | Visual mesh versus the SDF collision representation used in Isaac Sim | | 13
7 Passive wrist implemented as a four-link mechanism that preserves the plug orientation while the
| shoulder and elbow joints move | | 14
8 | Manipulator geometry, link lengths, and the passive leveling wrist | | 14
9 | Frame assignment and the planar (ρ, z) projection used in the forward kinematics | | 15
10 | Geometric inverse kinematics: law-of-cosines construction and the two elbow branches | | 15
11 | Manipulability distribution and singular configurations of the manipulator | | 16
12 Two-link dynamic model and the configuration-dependent gravity load | | 17
13 Joint identification: step-response fit, free-oscillation decay, and frequency response | | 18
14 | Motor identification: coast-down decay and no-load electrical regression | | 18
15 Validation of the digital twin against the hardware and the reference kinematics | | 19
16 Transform (TF) tree. Solid edges are estimated or static-rigid; the dashed map→odom edge is
| corrected discontinuously by SLAM loop closures, whereas odom→base_link is the smooth, slowly
| drifting dead-reckoned pose T O
| B . Static extrinsics below base_link are fixed by calibration. . . . | 29
17 Differential-drive geometry. Wheels of radius r sit on the drive axle at ±Lt/2 from base_link
| (B). For nonzero yaw rate the body rotates about the instantaneous center of curvature (ICC) at
| signed turn radius Ricc = v/ω; the dashed arc is the resulting constant-curvature path | | 31
18 Dynamic visual SLAM pipeline. The frontend (top) runs at camera rate: ORB extraction, the
| metric depth gate, brute-force Hamming matching, and depth-aided PnP/RANSAC produce a per-
| frame pose and decide whether the frame becomes a keyframe. The backend (bottom) associates
| keyframe observations, triangulates new landmarks, and re-optimizes the 10-keyframe window by
| sparse bundle adjustment; the refined map seeds the next frame and is published as TF and
| odometry. Dynamic observations are culled before matching (Equation (58)) | | 32
19 Volumetric mapping pipeline. Registered metric depth and the body pose are fused into a TSDF
| by the weighted average of Equation (62); the truncated field is converted into a Euclidean dis-
| tance field by wavefront propagation, from which a colored surface mesh and a two-dimensional
| navigation slice are extracted; the slice is inflated into the Nav2 costmap of Equation (65) | | 37
20 Nested motion-control loop. The planner body twist (v, ω) is mapped by the inverse kinematics
(77) to wheel-speed setpoints, regulated by a PI law with a speed observer on the PRIZM controller,
| amplified through the PWM H-bridge to motor voltage, and converted to wheel torque that drives
| the reduced base dynamics (86)–(87). Encoder feedback closes the inner velocity loop and feeds
| wheel odometry to the perception subsystem (Section B); the realised base motion delivers the
| parked pose to the manipulator subsystem | | 43
21 Plugging finite-state machine. The eye-in-hand policy drives Visual Alignment; the Insertion
| Thrust is validated by the plug-mounted limit switch, whose closure b=1 confirms electrical seating
| and advances the machine to charging, while a thrust that fails to close the switch returns control
| to alignment for another attempt | | 45
22 End-to-end data flow of one charging mission. Red blocks are physical devices on the Raspberry Pi
| or ESP32; blue blocks are laptop computations. Each edge is annotated with the data product it
| carries, from raw RGB-D imagery through the global pose, the distance field, the planned twist, the
parked base, the socket-hole bearings, the joint commands, and finally the limit-switch confirmation. 46 23 Dynamic VSLAM: (a) RGB-D input with a moving object, (b) dynamic-object mask and rejected
| features (green = static inliers, orange = rejected), (c) reconstructed map with ground-truth vs.
| estimated trajectory | | 57
24 Experiment 1: dynamic objects should be visibly excluded from the static mapping or tracking set. 57 25 Top-down L-shaped trajectory comparison for Experiment 1. (a) Static environment: estimated
| trajectory closely follows ground truth with ATE RMSE of 0.079 m. (b) Dynamic-object condition:
| drift increases to ATE RMSE of 0.121 m, with brief excursions during pedestrian crossings that
| recover once the occluder leaves the field of view | | 57

4

26 Quantitative SLAM results for Experiment 1. Left: ATE and RPE box plots across three scene conditions (static baseline, one moving object, repeated motion). Right: tracking rate and trackingloss count for the same conditions. Dynamic filtering maintains tracking above 95.8% even under
| repeated occlusion | | 58
27 | Success rate and errors for Experiment 2 | | 58
28 Translation and yaw error vs. range under three lighting conditions, with detection rate | | 59
29 (a) Success rate and travel time; (b) final position and heading error (95% CI) for the three
| navigation scenarios | | 59
30 | Robot Design | | 60
31 Arm positioning and passive-wrist leveling results for Experiment 4. (a) Top-down workspace error
| map showing mean plug-tip position error (mm) at a 5×3 target grid. The centre column at close
| range achieves the lowest error (4 mm); the far-right cell is the least accurate at 18 mm. (b) Passive-
| wrist orientation error by workspace zone; the median remains below the 5° specification limit in
| all zones, confirming the mechanical coupling assumption | | 61
32 Terminal Positioning Error for Experiment 5 | | 61
33 Domain-randomization robustness ablation for Experiment 6 (250 episodes per condition). (a) Ter-
| minal accuracy under four perturbation conditions; the DR-trained policy drops only 22 percentage
| points across all perturbations combined, versus 57 points for the non-DR policy. (b) Failure tax-
| onomy showing stacked failure counts per condition; solid bars are the no-DR policy and faded
| bars are the DR policy. The DR policy eliminates most timeout and target-not-reached failures at
| the cost of a modest increase in oscillation terminations under combined perturbation | | 62
34 | Final Insertion | | 62
35 | Real Twin | | 63
36 End-to-end mission evidence for Experiment 8. (a) Top-down map showing the base trajectory
| from the start pose (green circle) to the charging station (red star), with phase change markers
| overlaid. A pillar obstacle is avoided via the costmap planner. (b) State-machine phase timeline
| for a representative successful mission (82 s total); SLAM and navigation consume the largest share
| of mission time (42 s), while base refinement (8 s) and insertion (9 s) are comparatively brief. . . . | 64

5

### List of Tables

1 | Mobile-robot base specifications measured in Isaac Sim 5.1 (PhysX, USD world bounds) | | 12
2 | Wheel specifications of the mobile base | | 12
3 | Identified TorqueNADO motor parameters | | 18
4 | Pipeline rates and resources | | 25
5 | Principal reference frames and symbols used throughout the chapter | | 26
6 ROS 2 topic interface. Hosts: Pi = Raspberry Pi 4, L = laptop, E = ESP32. The PRIZM is not
| a ROS node; its data enter the graph through prizm_bridge on the Pi. (∗) custom message. . . | 28
7 | TorqueNADO PMDC drive parameters (per motor) used in Equations (88) and (89) | | 42
8 Nested control and estimation loops of the integrated charging agent, ordered from the fast, local
| inner loops to the slow, global outer loops. The inner the loop, the higher its rate and the closer
| it runs to the actuator | | 47
9 The four registered reinforcement-learning tasks. The state-based tasks share a 12-dimensional
| observation and a three-dimensional action; VisionInsert uses an asymmetric actor–critic in
| which the camera-only actor observes 15 dimensions while the privileged critic retains the 12-
| dimensional ground-truth state | | 48
10 | Digital-twin settings that determine the simulated command interface and contact behavior. . . . | 49
11 | Geometric and sensing elements of one simulated charging scene | | 49
12 Reward terms and weights for the joint-delta reach and insert tasks of (VI.5). The insert task
| inherits the reach weights except where a sharpened value is listed; the sharper fine attractor,
| stronger centering well, and finer joint step move the optimum from the tolerance edge to dead
| centre | | 51
13 Per-task PPO hyperparameters for the four registered charging-arm environments. Values common
| to all tasks are listed once; task-specific values are shown per column. Buffer size is N × T
| transitions per iteration. Hidden dimensions apply to both the actor and the critic | | 52
14 | Evaluation protocol and development observations | | 53
15 | Interface quantities held consistent between training and deployment | | 54

### 16 Implementation and validation status of each system component. HW = implemented and

| tested on physical robot. SIM = implemented and validated inside Isaac Sim only. PAR-
| TIAL = implementation started; core logic works but edge cases or calibration are incomplete.
| PLANNED = design is specified; code not yet written | | 55
17 | Experimental sequence and the evidence required from each stage | | 56
18 VSLAM accuracy and continuity (n = 32 runs per condition) | | 58
19 | Socket pose estimation vs. lighting (range 0.2–1.2 m) | | 58
20 Approach navigation results (n = 30 trials per scenario) | | 59

6

### I. Introduction

Research on electric vehicles (EVs) has grown rapidly in recent years, and robotic technology is being developed to support this growth. One important direction is the automation of EV charging, where robotic and electronic systems plug and unplug the charging connector automatically. In this process, the connector must be inserted into the vehicle charging socket with proper alignment.
Automated charging stations are therefore not only an energy-transfer problem but also a robotic manipulation problem: the charging connector must be guided toward the socket, aligned with the inlet, and inserted through a controlled motion. Previous studies on EV charging connectors have shown that the plugging and unplugging process strongly affects the safety and efficiency of charging, and that the motion profile during insertion is important for designing reliable robotic charging systems. Whereas that prior work characterizes the connection through force and torque, this project is motivated by the smoothness and safety of the plug-in motion, expressed through acceleration and jerk. Acceleration describes how quickly the connector velocity changes, and jerk is the rate of change of acceleration. Both quantities indicate motion smoothness: keeping them bounded reduces abrupt movements and improves the safety of insertion.
At the same time, the robot must operate in an environment that may contain moving objects. Simultaneous localization and mapping (SLAM) is an established research field in robotics, but many SLAM methods rely on the static-world assumption. This assumption limits their use in real-world environments that are dynamic, unstructured, and only partially known. Dynamic visual SLAM addresses this limitation by allowing the robot to build a map while accounting for moving objects in the scene. A mobile charging robot needs this capability, since it must navigate toward the charging area, maintain a stable representation of the environment, and avoid treating dynamic objects as reliable static landmarks.
This project studies a laboratory-safe version of autonomous plug-in charging using a differential mobile base, a base-mounted RGB-D camera for dynamic visual SLAM, a 3-DoF robotic arm, and an eye-in-hand RGB camera for local socket observation. The mobile base uses the SLAM stage to approach the target socket and maintain a map of the surrounding environment. The arm then performs the local alignment and insertion task. During this final phase, the end-effector mounting plane is kept parallel to the mobile-base (xb-yb) plane, which simplifies the plug-socket alignment problem and makes the experiment suitable for a controlled laboratory setup.
The main objective of this work is to define and evaluate a robotic pipeline for simplified plug-in charging. The pipeline is organized into six implementation stages: mobile-base navigation, dynamic visual SLAM, local socket observation, plug-socket pose estimation, final alignment, and insertion. The study also defines the task phases, observation and action spaces, safety limits, reward function, and evaluation metrics. Motion smoothness and safety remain a guiding concern, with acceleration and jerk taken as indicators of how smooth the insertion motion is. A successful system should therefore not only reach the socket but also do so through a stable, smooth, and safe motion.

7

### II. Objectives

The primary aim of this thesis is to design, implement, and validate a complete robotic pipeline for autonomous conductive EV charging in a controlled laboratory environment. The objectives are structured to address each major subsystem in sequence, from the physical platform through to full mission integration.
The first objective is to design and fabricate a compact differential-drive mobile robot platform capable of operating safely inside a structured indoor space. This encompasses the mechanical design of the mobile base, a three-degree-of-freedom robotic arm, and a passive compliant wrist that absorbs residual misalignment during plug-socket contact. The platform must also be modelled as a digital twin inside Isaac Sim, with kinematics and joint dynamics validated against the physical hardware before deployment.
The second objective is to develop and integrate a dynamic visual SLAM pipeline that maintains stable robot localization and a consistent static map of the environment even when moving objects are present in the scene. The pipeline must classify and suppress dynamic features so that they do not contaminate the map or corrupt the pose estimates that the navigation module relies on during approach.
The third objective is to implement socket detection and local pose estimation from the eye-in-hand RGB camera using a category-level keypoint-based object pose estimator. The estimated socket pose must be accurate enough, across a range of standoff distances, yaw angles, and lighting conditions, to bring the plug tip within the verified capture range of the fine-alignment controller without manual positioning.
The fourth objective is to implement autonomous point-to-point navigation from a known base station to the target parking bay using the ROS 2 Navigation 2 stack with an MPPI local controller, operating on the costmap generated from the SLAM-derived voxel map. Navigation must succeed without collision and without operator intervention across all tested starting poses and obstacle configurations.
The fifth objective is to design and train a reinforcement-learning insertion policy using Proximal Policy Optimization in Isaac Lab that refines final plug-socket alignment and executes the contact phase of insertion. The policy must improve terminal alignment accuracy over the deterministic inverse-kinematics baseline and must produce smooth, bounded motion quantified through jerk and acceleration metrics throughout the insertion trajectory.
The sixth objective is to evaluate the sim-to-real transfer of the trained insertion policy on the physical robot through a structured hardware protocol spanning at least thirty trials across centred, left-offset, and right-offset initial conditions, and to identify the dominant failure modes that constrain physical performance.
The seventh and final objective is to integrate all subsystems — dynamic SLAM, global navigation, socket detection, base refinement, arm control, and RL insertion — into a single state-machine-governed pipeline and to demonstrate complete autonomous charging missions in the laboratory from an arbitrary start pose to confirmed plug seating, without manual intervention at any stage.

### III. Related Works

Hanai et al., working on robotic wrapping and deformable manipulation, proposed a framework that combines imitation learning and reinforcement learning. Their method uses demonstrations to obtain approximate toolcenter-point trajectories and then uses RL to tune force-control parameters. The shared learning logic, rather than the wrapping task itself, is what carries over to our work: a nominal trajectory constrains the search space while RL corrects the contact behavior. Their training procedure also separates simulation training from real-world force adaptation, which parallels our sim-to-real plan, in which Isaac Sim is the simulator [1].
Wang et al. studied complex contact-rich insertion and presented an adaptive imitation learning framework that treats insertion as a nonlinear, low-clearance operation with phase-dependent force requirements. The term “contact-rich insertion” is established in the robotics literature for tasks where contact is expected and must be regulated rather than avoided. They explain why pure imitation learning is insufficient when force profiles are difficult to acquire, and why pure RL can be unsafe, since random exploration may cause excessive collisions. Their solution combines a trajectory-level skill policy with a low-level force-learning policy and introduces dynamical movement primitives to generalize trajectories between related insertion tasks [2]. This supports a key design choice in our project: rather than inserting the plug with blind random RL, the plug follows a structured nominal path and RL is used mainly for corrections and contact adaptation.
Saputra et al. examined EV charging connector interaction, characterizing plugging and unplugging of a Type 2 AC EV connector using force/torque measurements. Their experiments with human operators showed that plugging requires a higher impulse than unplugging and that the force and torque profiles vary over time. They also modeled these profiles using polynomial, Fourier, and Gaussian fitting, with the Gaussian model giving the most accurate fit [3]. These results motivate our reward and safety design. Even though our laboratory socket is simplified, the plug-in stage should still be treated as a force-sensitive operation rather than a purely geometric motion.
For robotic charging systems, previous works have used computer vision, force sensing, and mobile manipulation to localize the charging inlet and perform connector insertion [4, 5, 6, 7, 8]. Such methods are highly relevant

8

because the charging task can be modeled as a peg-in-hole insertion problem with perception uncertainty. Many approaches focus on perception or local alignment, and fewer studies connect global mobile navigation, dynamicscene SLAM, and contact-rich arm insertion in a single prototype pipeline. This is the gap the present project targets, combining dynamic visual SLAM for the approach with reinforcement learning for the local alignment and insertion.

### IV. System Design

Task
The task starts with a mapping run inside the garage. Before charging requests are handled, the robot drives through the accessible lanes while the base-mounted RGB-D camera records depth images, and dynamic visual SLAM estimates the camera pose during this scan. From the depth images and poses, nvblox builds a 3-D voxel map of the garage and produces a 2-D costmap for navigation [9, 10]. The map represents the fixed parts of the garage, such as walls, pillars, lane boundaries, and the base station, and serves as the reference map during later charging runs.
At the start of each charging run, the robot sits at the base station, a fixed and known location in the garage map. The robot is connected there to charge its own battery, so its initial pose is known before it moves. When a vehicle enters the garage, the system receives its parking-bay location, which becomes the navigation goal. The goal is the parking area, not the charging socket, because the socket position is not known until the robot reaches the vehicle.
The global navigation stage moves the robot from the base station to the requested parking bay. A cost-aware A* planner in the ROS 2 Navigation 2 stack (Nav2) searches the costmap and creates a collision-free route [11]. Dynamic visual SLAM supplies the current base pose while the robot follows this route. For local control, Nav2 uses a Model Predictive Path Integral (MPPI) controller with the differential-drive motion model: at each control step it generates and scores short candidate trajectories, then sends the next linear and angular velocity command [12]. This navigation stack is first validated in Isaac Sim with the same base and sensor arrangement, then deployed on the physical robot through the ROS 2 command chain.
When the robot reaches the parking bay, it stops following the global route and begins the socket-search stage. A CenterPose detector finds the charging socket in the RGB image: it detects the object and its image keypoints, then estimates the pose of the trained socket class [13]. This RGB pose is combined with the depth image and the calibrated camera-to-base transform to obtain a coarse socket location in the base frame. The mobile base then makes small position and heading corrections until the socket lies inside the calibrated reachable workspace of the arm, the condition required before the arm begins the final alignment task.
After this base adjustment, the eye-in-hand camera provides the close-range view needed for the fine plug-socket estimate. The RL policy then corrects the remaining alignment error and performs the insertion motion. The policy is trained offline in Isaac Lab, with socket pose, base stopping error, contact conditions, and sensor effects varied during training [14, 15]. No online RL training is performed on the physical arm; the real robot runs the saved policy for inference, together with the predefined safety limits.

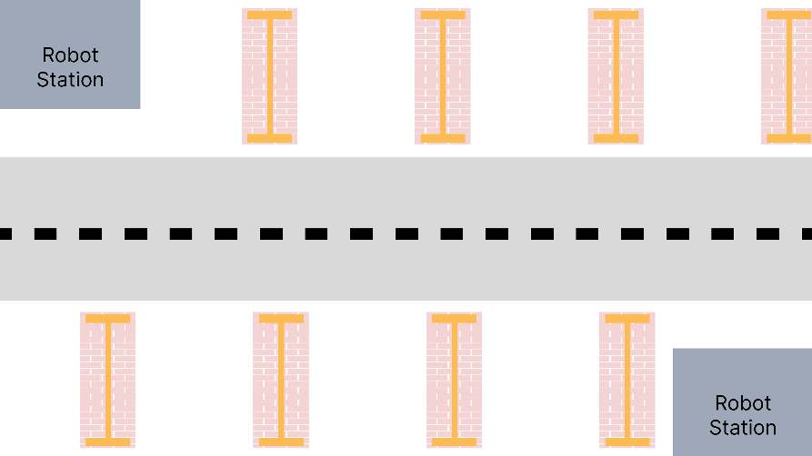
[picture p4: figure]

FIGURE 1: Garage charging task sequence from mapping and base-station departure to local socket alignment and plug insertion.

9

Map garage
and initialise at
base station

Navigate to
requested bay
with SLAM + Nav2

Detect socket
and refine base
stopping pose

Eye-in-hand alignment
and guarded
plug insertion

FIGURE 2: Operational sequence of the simplified autonomous charging task. Global navigation ends at the parking bay; the local perception and insertion stages then handle the socket-specific alignment.
Mechanical Design and Modeling
The mechanical design presents the physical platform and the models that describe its motion and loading. It addresses the mechanical architecture, the CAD and digital twin pipeline, the kinematic and dynamic models of the manipulator, the collision representation, and the experimental identification of the joint and motor parameters. All kinematic and dynamic relations were verified symbolically and numerically against the implementation
in works/.

Mechanical System Overview
The robot is a mobile manipulator built from four subsystems: a differential-drive mobile base, a custom 3-DoF serial manipulator, an end-effector carrying the charging plug, and a sensor mount fixing an eye-in-hand camera to the wrist. Together they form a single kinematic chain, so every frame is expressed in one unified description. The driving design objectives are lightweight construction, ease of manufacturing, accurate simulation, and ROS 2 / Isaac Sim compatibility for autonomous charging experiments.

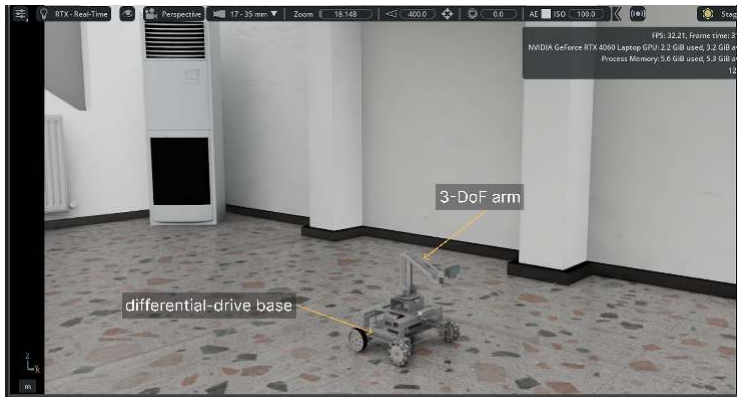
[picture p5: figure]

FIGURE 3: Overview of the mobile-manipulator platform and its four subsystems.

CAD Design and Digital-Twin Development
Every link was modeled in Blender as a separate mesh and arranged into the parent–child hierarchy of the physical chain. The Phobos add-on exports this tree to URDF, generating the joint hierarchy, link definitions, inertial properties (<inertial> tags), and collision models. The same workflow is used for the base and the arm, producing one consistent description for ROS 2 and the Isaac Sim digital twin.

Mobile Robot Mechanical Model
The base is a differential drive. Two independently driven rear wheels set the linear and angular velocity through the sum and difference of their speeds, while passive front omni wheels provide support. The rear wheels are driven by TorqueNADO DC gear-motors, identified in Section 11). Mass properties are taken from CAD: the volume gives the mass,
m = ρ V, | (1)
and integration over the solid gives the center of mass and inertia tensor,

rc =

1
m

Z

B

ρ r dV, I =

Z

B

ρ
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

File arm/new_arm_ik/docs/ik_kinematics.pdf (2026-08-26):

## Forward and Inverse Kinematics of the new arm Manipulator

Robot description: new arm description Solver package: new arm ik

2026-05-31

Abstract

This document describes the kinematics of the new arm, a 4-DOF revolute manipulator, as implemented in the new arm ik ROS 2 package. The forward kinematics is built directly from the robot’s URDF so that the solver and the model rendered in RViz are identical by construction. The inverse kinematics is formulated as a bounded nonlinear least-squares problem with a continuity-preserving regularizer and a random-restart fallback. We also document a tuning fix that reduced the median position residual from 20 mm to below 1 µm on reachable targets.

## Contents

1 Robot model | 1
2 Rotation primitives | 2
3 Forward kinematics | 3
4 Inverse kinematics | 3
5 Solver parameters | 4
6 The tuning fix | 4
7 ROS 2 integration | 5
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

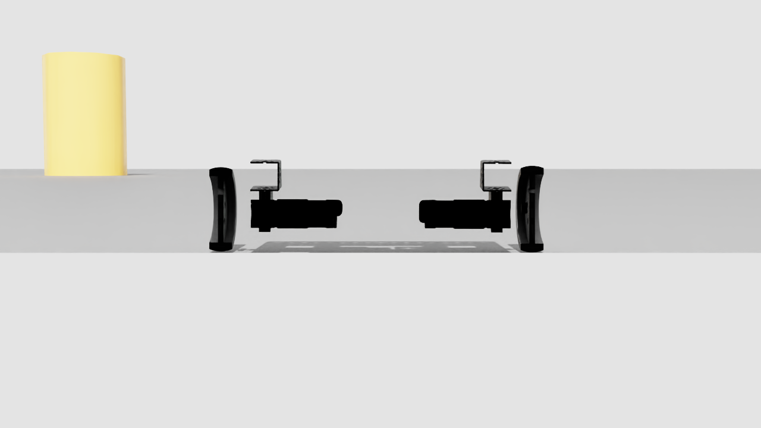
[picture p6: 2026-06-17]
renders/rescaled2_side.png

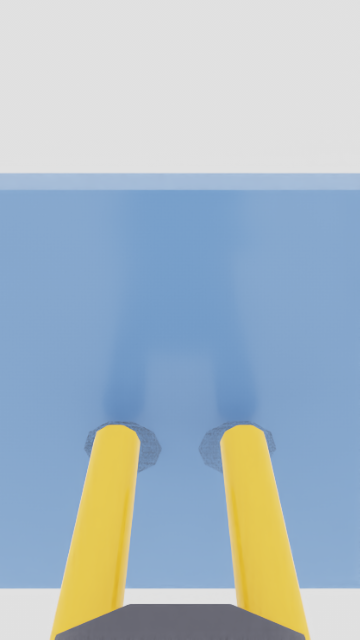
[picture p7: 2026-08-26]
docs/images/insert_wristcam.png

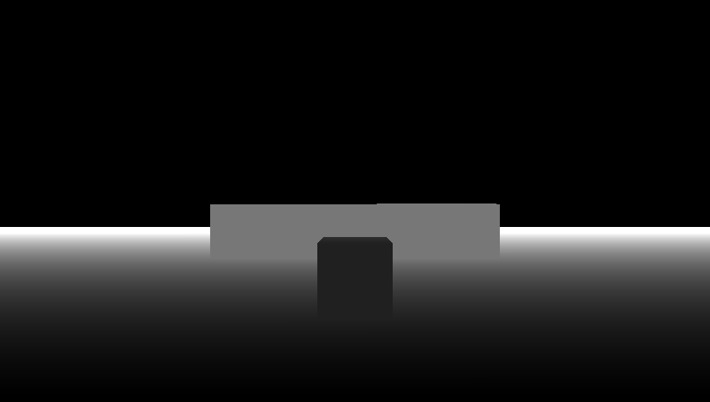
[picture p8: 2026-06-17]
renders/topic_depth.png

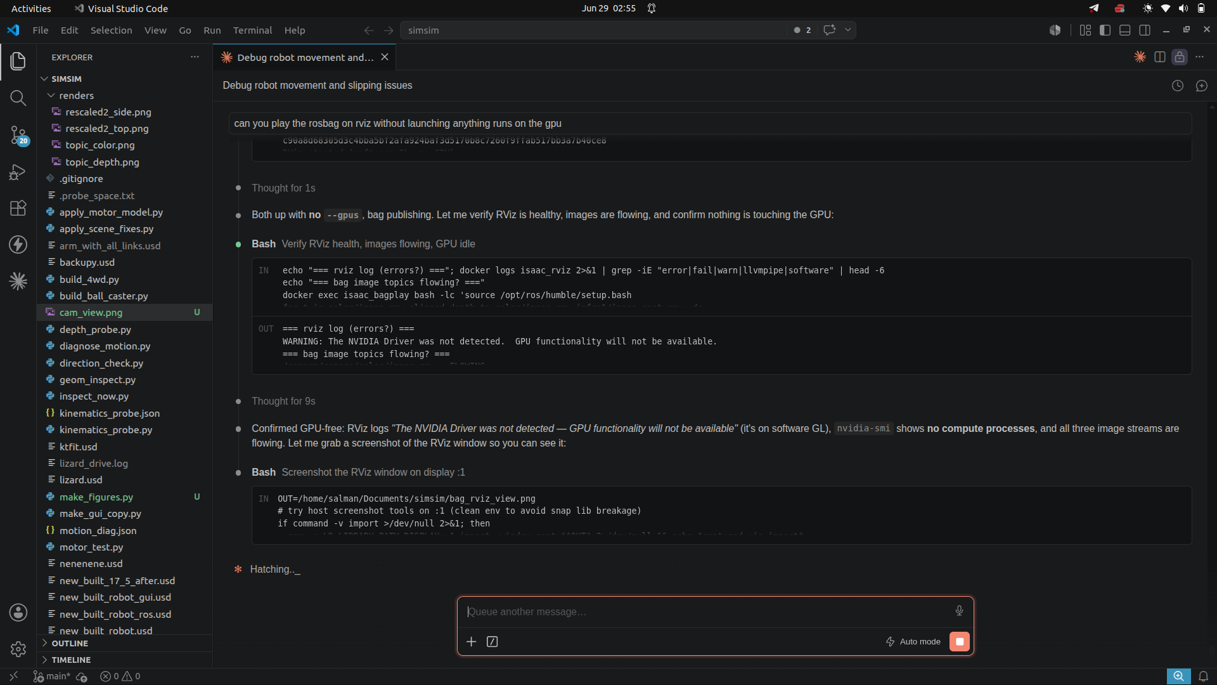
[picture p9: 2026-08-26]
bag_rviz_view.png

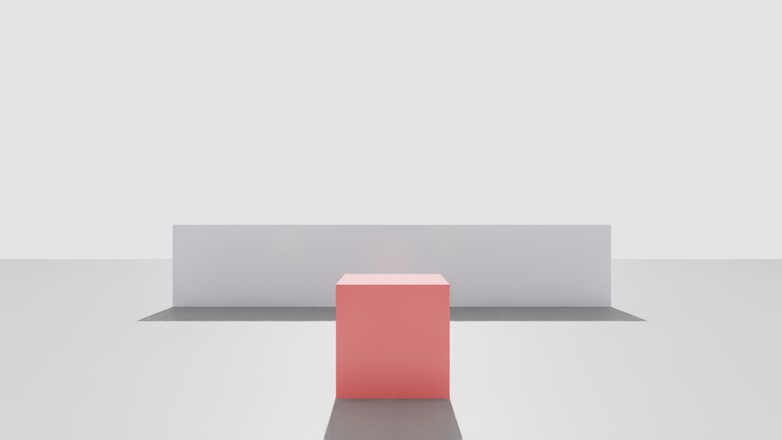
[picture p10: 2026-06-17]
renders/topic_color.png

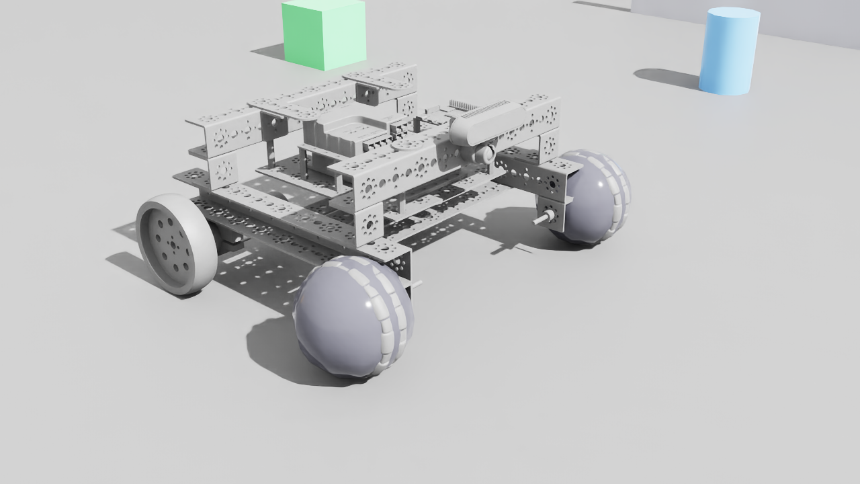
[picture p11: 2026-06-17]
renders/ballcaster_iso.png

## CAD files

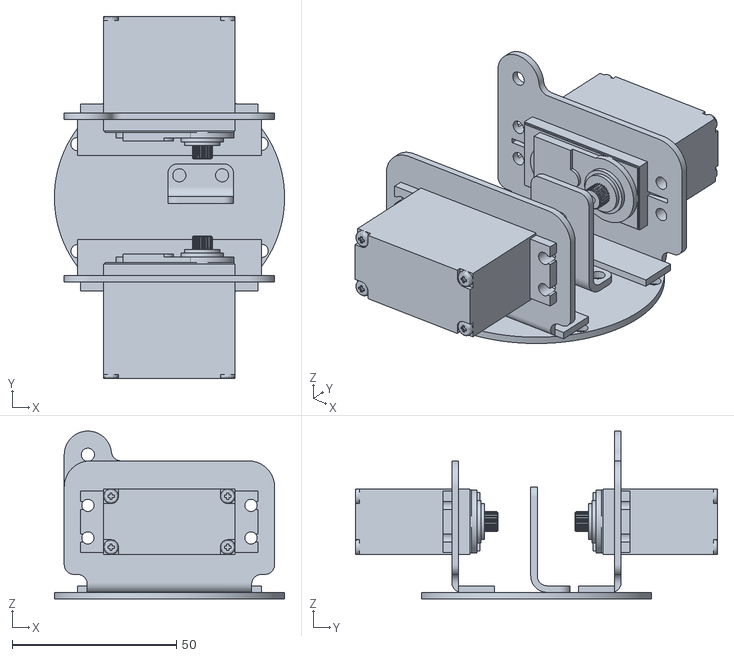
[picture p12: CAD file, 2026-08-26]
arm/new_arm_description/meshes/stl/after_base_full.stl
70.0 x 110.1 x 51.0

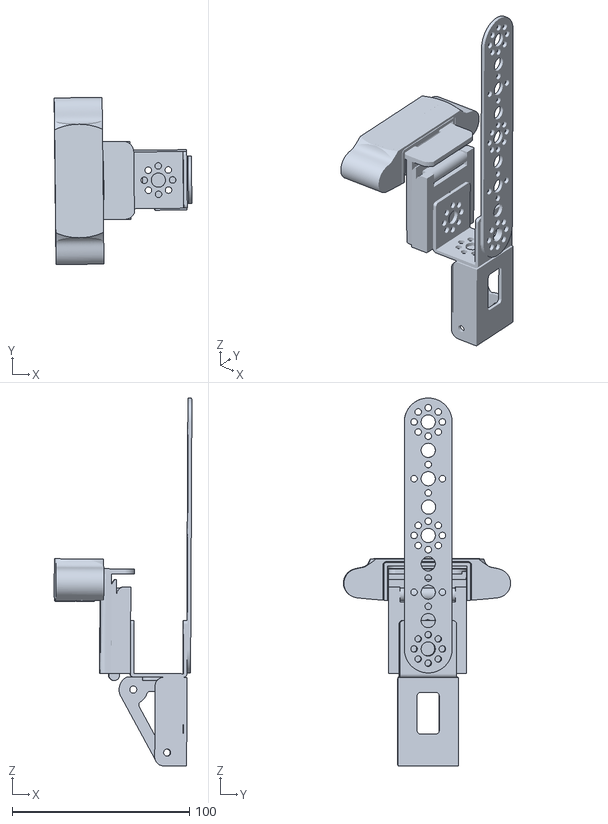
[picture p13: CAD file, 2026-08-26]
arm/New_arm/meshes/stl/end_effector.stl
77.6 x 94.3 x 207.5

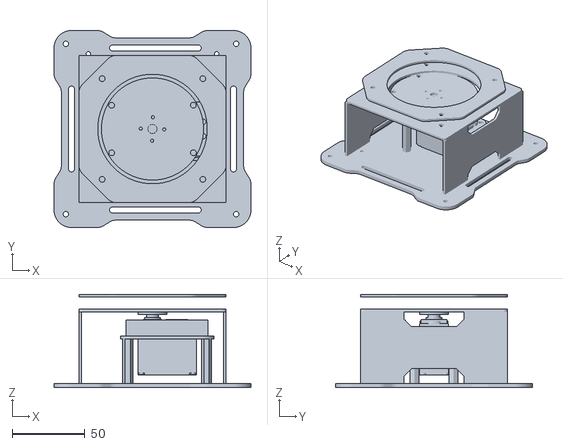
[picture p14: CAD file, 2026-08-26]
arm/New_arm/meshes/stl/arm base.stl
135.0 x 135.0 x 64.0

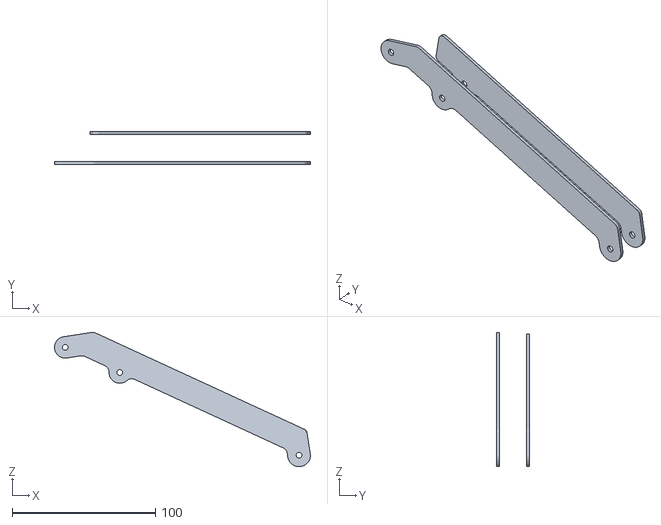
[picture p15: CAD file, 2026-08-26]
arm/new_arm_description/meshes/stl/link2.stl
179.0 x 23.0 x 93.9

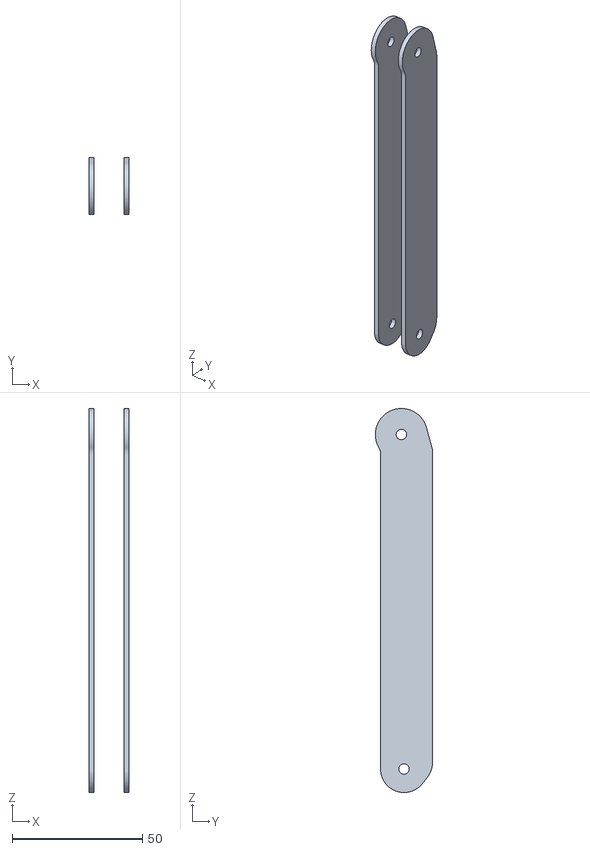
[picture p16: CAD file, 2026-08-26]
arm/New_arm/meshes/stl/link1.stl
15.5 x 22.0 x 147.4

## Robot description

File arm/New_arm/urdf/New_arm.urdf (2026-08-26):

<robot name="New_arm" version="1.0">
  <joint name="after base full_link_joint" type="revolute">
    <limit lower="-3.14000" upper="3.14000" effort="0.00000" velocity="0.00000"/>
    <origin rpy="0.00000 0.00000 0.00000" xyz="0.43239 -1.84063 83.96122"/>
    <parent link="arm_base_link"/>
    <child link="after_base_full_link"/>
    <axis xyz="0.00000 0.00000 1.00000"/>
  </joint>
  <joint name="link1_link_joint" type="revolute">
    <limit lower="-3.14000" upper="3.14000" effort="0.00000" velocity="0.00000"/>
    <origin rpy="0.00000 0.00000 0.00000" xyz="8.14224 -0.43239 1.61718"/>
    <parent link="after_base_full_link"/>
    <child link="link1_link"/>
    <axis xyz="0.00000 1.00000 0.00000"/>
  </joint>
  <joint name="link2_link_joint" type="revolute">
    <limit lower="-3.14000" upper="3.14000" effort="0.00000" velocity="0.00000"/>
    <origin rpy="0.00000 0.00000 0.00000" xyz="1.00000 -8.56000 128.39612"/>
    <parent link="link1_link"/>
    <child link="link2_link"/>
    <axis xyz="0.00000 1.00000 0.00000"/>
  </joint>
  <joint name="end_effector_link_joint" type="revolute">
    <limit lower="-3.14000" upper="3.14000" effort="0.00000" velocity="0.00000"/>
    <origin rpy="0.00000 0.00000 0.00000" xyz="125.31939 10.99000 -57.78452"/>
    <parent link="link2_link"/>
    <child link="end_effector_link"/>
    <axis xyz="0.00000 1.00000 0.00000"/>
  </joint>
  <link name="arm_base_link">
    <collision name="arm base_collision">
      <origin rpy="0.00000 0.00000 0.00000" xyz="0.00000 0.00000 0.00000"/>
      <geometry>
        <mesh filename="../meshes/stl/arm base.stl" scale="1.00000 1.00000 1.00000"/>
      </geometry>
    </collision>
    <visual name="arm base">
      <material name="None"/>
      <origin rpy="0.00000 0.00000 0.00000" xyz="0.00000 0.00000 0.00000"/>
      <geometry>
        <mesh filename="../meshes/stl/arm base.stl" scale="1.00000 1.00000 1.00000"/>
      </geometry>
    </visual>
  </link>
  <link name="after_base_full_link">
    <collision name="after base full_collision">
      <origin rpy="0.00000 0.00000 0.00000" xyz="-0.00000 0.00000 0.00000"/>
      <geometry>
        <mesh filename="../meshes/stl/after base full.stl" scale="1.00000 1.00000 1.00000"/>
      </geometry>
    </collision>
    <visual name="after base full">
      <material name="None"/>
      <origin rpy="0.00000 0.00000 0.00000" xyz="-0.00000 0.00000 0.00000"/>
      <geometry>
        <mesh filename="../meshes/stl/after base full.stl" scale="1.00000 1.00000 1.00000"/>
      </geometry>
    </visual>
  </link>
  <link name="link1_link">
    <collision name="link1_collision">
      <origin rpy="0.00000 0.00000 1.57080" xyz="0.00000 0.00000 -0.00001"/>
      <geometry>
        <mesh filename="../meshes/stl/link1.stl" scale="1.00000 1.00000 1.00000"/>
      </geometry>
    </collision>
    <inertial>
      <inertia ixx="134.79547" ixy="-0.00000" ixz="-1.35022" iyy="134.47944" iyz="-0.00000" izz="5.42704"/>
      <origin rpy="0.00000 0.00000 0.00000" xyz="-0.84107 2.90000 64.94700"/>
      <mass value="0.10000"/>
    </inertial>
    <visual name="link1">
      <material name="None"/>
      <origin rpy="0.00000 0.00000 1.57080" xyz="0.00000 0.00000 0.00000"/>
      <geometry>
        <mesh filename="../meshes/stl/link1.stl" scale="1.00000 1.00000 1.00000"/>
      </geometry>
    </visual>
  </link>
  <link name="link2_link">
    <collision name="link2_collision">
      <origin rpy="0.00000 0.00000 0.00000" xyz="-0.00000 -0.00000 0.00003"/>
      <geometry>
        <mesh filename="../meshes/stl/link2.stl" scale="1.00000 1.00000 1.00000"/>
      </geometry>
    </collision>
    <inertial>
      <inertia ixx="46.58794" ixy="-5.28941" ixz="75.92046" iyy="220.45627" iyz="1.19376" izz="187.76503"/>
      <origin rpy="0.00000 0.00000 0.00000" xyz="51.92619 10.92440 -15.11619"/>
      <mass value="0.10000"/>
    </inertial>
    <visual name="link2">
      <material name="None"/>
      <origin rpy="0.00000 0.00000 0.00000" xyz="-0.00000 -0.00000 0.00000"/>
      <geometry>
        <mesh filename="../meshes/stl/link2.stl" scale="1.00000 1.00000 1.00000"/>
      </geometry>
    </visual>
  </link>
  <link name="end_effector_link">
    <collision name="end_effector_collision">
      <origin rpy="-0.00000 1.57080 0.00000" xyz="-0.00002 -0.00000 -0.00003"/>
      <geometry>
        <mesh filename="../meshes/stl/end_effector.stl" scale="1.00000 1.00000 1.00000"/>
      </geometry>
    </collision>
    <visual name="end_effector">
      <material name="None"/>
      <origin rpy="-0.00000 1.57080 0.00000" xyz="0.00001 -0.00000 -0.00001"/>
      <geometry>
        <mesh filename="../meshes/stl/end_effector.stl" scale="1.00000 1.00000 1.00000"/>
      </geometry>
    </visual>
  </link>
</robot>

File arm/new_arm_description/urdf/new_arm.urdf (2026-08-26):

<?xml version="1.0"?>
<robot name="new_arm">

  <material name="grey">
    <color rgba="0.6 0.6 0.6 1.0"/>
  </material>
  <material name="orange">
    <color rgba="0.9 0.5 0.1 1.0"/>
  </material>
  <material name="blue">
    <color rgba="0.2 0.4 0.9 1.0"/>
  </material>

  <link name="arm_base_link">
    <visual>
      <origin xyz="0 0 0" rpy="0 0 0"/>
      <geometry>
        <mesh filename="package://new_arm_description/meshes/stl/arm_base.stl" scale="0.001 0.001 0.001"/>
      </geometry>
      <material name="grey"/>
    </visual>
    <collision>
      <origin xyz="0 0 0" rpy="0 0 0"/>
      <geometry>
        <mesh filename="package://new_arm_description/meshes/stl/arm_base.stl" scale="0.001 0.001 0.001"/>
      </geometry>
    </collision>
  </link>

  <joint name="after_base_full_joint" type="revolute">
    <parent link="arm_base_link"/>
    <child link="after_base_full_link"/>
    <origin xyz="0.00043239 -0.00184063 0.08396122" rpy="0 0 0"/>
    <axis xyz="0 0 1"/>
    <limit lower="-3.14" upper="3.14" effort="10.0" velocity="1.0"/>
  </joint>

  <link name="after_base_full_link">
    <visual>
      <origin xyz="0 0 0" rpy="0 0 0"/>
      <geometry>
        <mesh filename="package://new_arm_description/meshes/stl/after_base_full.stl" scale="0.001 0.001 0.001"/>
      </geometry>
      <material name="orange"/>
    </visual>
    <collision>
      <origin xyz="0 0 0" rpy="0 0 0"/>
      <geometry>
        <mesh filename="package://new_arm_description/meshes/stl/after_base_full.stl" scale="0.001 0.001 0.001"/>
      </geometry>
    </collision>
    <inertial>
      <origin xyz="0 0 0.02" rpy="0 0 0"/>
      <mass value="0.3"/>
      <inertia ixx="0.0005" ixy="0" ixz="0" iyy="0.0005" iyz="0" izz="0.0005"/>
    </inertial>
  </link>

  <joint name="link1_joint" type="revolute">
    <parent link="after_base_full_link"/>
    <child link="link1_link"/>
    <origin xyz="0.00814224 -0.00043239 0.00161718" rpy="0 0 0"/>
    <axis xyz="0 1 0"/>
    <limit lower="-3.14" upper="3.14" effort="10.0" velocity="1.0"/>
  </joint>

  <link name="link1_link">
    <visual>
      <origin xyz="0 0 0" rpy="0 0 1.57080"/>
      <geometry>
        <mesh filename="package://new_arm_description/meshes/stl/link1.stl" scale="0.001 0.001 0.001"/>
      </geometry>
      <material name="grey"/>
    </visual>
    <collision>
      <origin xyz="0 0 0" rpy="0 0 1.57080"/>
      <geometry>
        <mesh filename="package://new_arm_description/meshes/stl/link1.stl" scale="0.001 0.001 0.001"/>
      </geometry>
    </collision>
    <inertial>
      <origin xyz="-0.00084107 0.00290 0.06494700" rpy="0 0 0"/>
      <mass value="0.1"/>
      <inertia ixx="0.000135" ixy="0" ixz="0" iyy="0.000134" iyz="0" izz="0.0000054"/>
    </inertial>
  </link>

  <joint name="link2_joint" type="revolute">
    <parent link="link1_link"/>
    <child link="link2_link"/>
    <origin xyz="0.001 -0.00856 0.12839612" rpy="0 0 0"/>
    <axis xyz="0 1 0"/>
    <limit lower="-3.14" upper="3.14" effort="10.0" velocity="1.0"/>
  </joint>

  <link name="link2_link">
    <visual>
      <origin xyz="0 0 0" rpy="0 0 0"/>
      <geometry>
        <mesh filename="package://new_arm_description/meshes/stl/link2.stl" scale="0.001 0.001 0.001"/>
      </geometry>
      <material name="blue"/>
    </visual>
    <collision>
      <origin xyz="0 0 0" rpy="0 0 0"/>
      <geometry>
        <mesh filename="package://new_arm_description/meshes/stl/link2.stl" scale="0.001 0.001 0.001"/>
      </geometry>
    </collision>
    <inertial>
      <origin xyz="0.05192619 0.01092440 -0.01511619" rpy="0 0 0"/>
      <mass value="0.1"/>
      <inertia ixx="0.0000466" ixy="0" ixz="0.0000759" iyy="0.00022" iyz="0" izz="0.000188"/>
    </inertial>
  </link>

  <joint name="end_effector_joint" type="revolute">
    <parent link="link2_link"/>
    <child link="end_effector_link"/>
    <origin xyz="0.12531939 0.01099 -0.05778452" rpy="0 0 0"/>
    <axis xyz="0 1 0"/>
    <limit lower="-3.14" upper="3.14" effort="5.0" velocity="1.0"/>
  </joint>

  <link name="end_effector_link">
    <visual>
      <origin xyz="0 0 0" rpy="0 1.57080 0"/>
      <geometry>
        <mesh filename="package://new_arm_description/meshes/stl/end_effector.stl" scale="0.001 0.001 0.001"/>
      </geometry>
      <material name="orange"/>
    </visual>
    <collision>
      <origin xyz="0 0 0" rpy="0 1.57080 0"/>
      <geometry>
        <mesh filename="package://new_arm_description/meshes/stl/end_effector.stl" scale="0.001 0.001 0.001"/>
      </geometry>
    </collision>
    <inertial>
      <origin xyz="0 0 0" rpy="0 0 0"/>
      <mass value="0.05"/>
      <inertia ixx="0.0001" ixy="0" ixz="0" iyy="0.0001" iyz="0" izz="0.0001"/>
    </inertial>
  </link>

</robot>

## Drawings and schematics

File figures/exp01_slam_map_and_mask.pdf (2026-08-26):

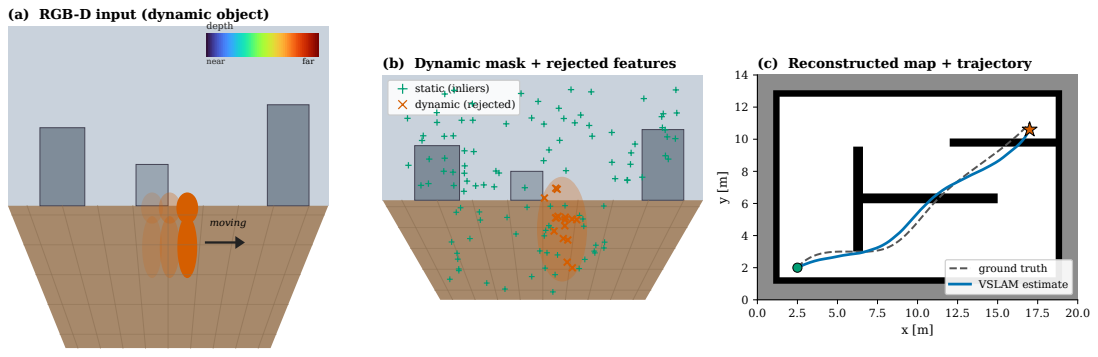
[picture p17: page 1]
depth; near; far; moving; static (inliers) dynamic (rejected); ground truth VSLAM estimate

(a) RGB-D input (dynamic object)

(b) Dynamic mask + rejected features

(c) Reconstructed map + trajectory

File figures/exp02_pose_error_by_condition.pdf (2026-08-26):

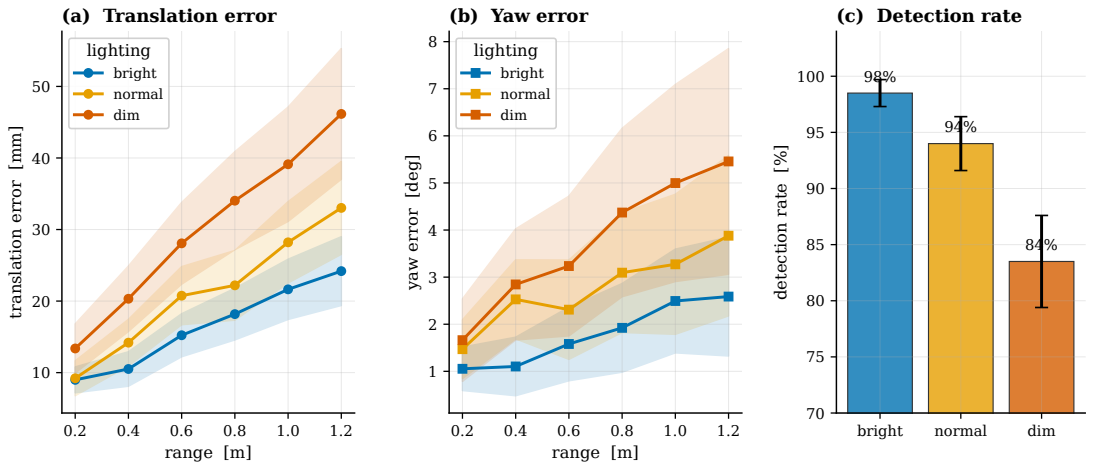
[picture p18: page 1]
range [m]; (a) Translation error; lighting bright normal dim; (b) Yaw error; bright; normal; dim; detection rate [%]; (c) Detection rate

translation error [mm]

yaw error [deg]

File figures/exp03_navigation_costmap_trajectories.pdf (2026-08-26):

## Navigation costmap with planned (– –) and executed (—) trajectories

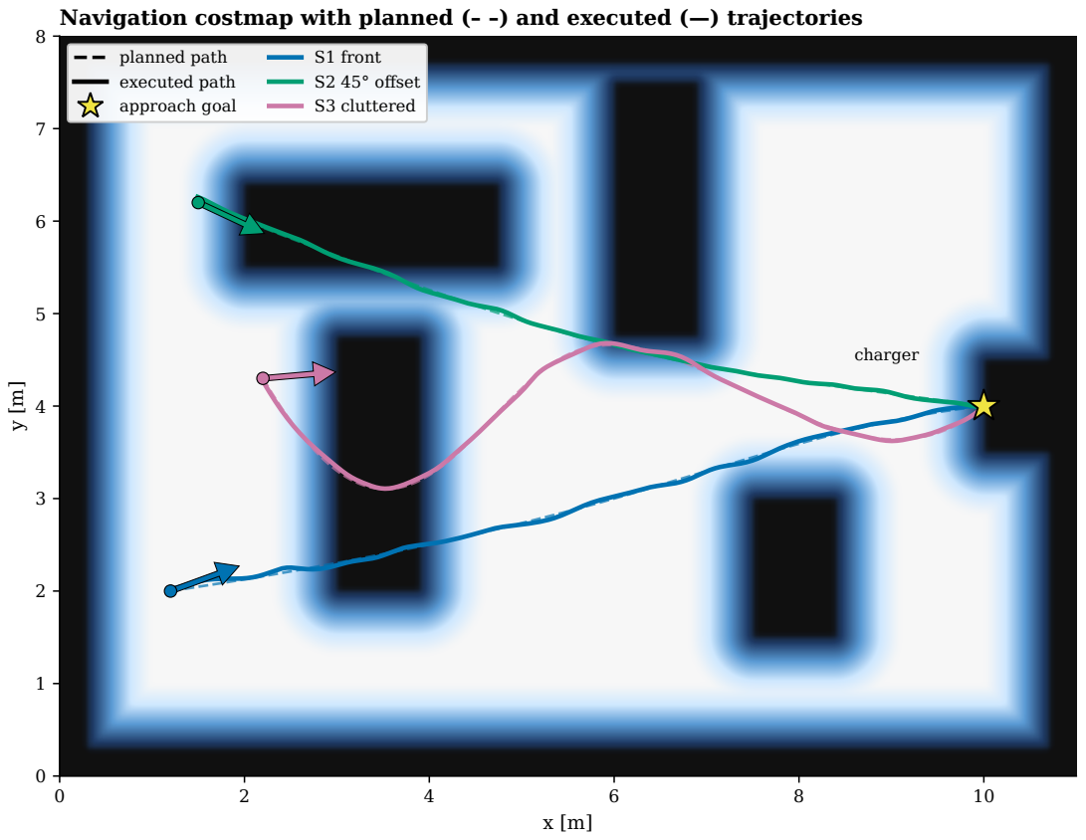
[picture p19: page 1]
charger; planned path executed path approach goal; S1 front S2 45° offset S3 cluttered

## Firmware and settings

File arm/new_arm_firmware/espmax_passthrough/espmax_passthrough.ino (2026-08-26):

// espmax_passthrough — ESP32 micro-ROS joint/servo pass-through for the ESPMax arm.
//
// Replaces the stock kinematics_move.ino "/arm_position -> onboard IK" behaviour.
// Here the ESP32 is a DUMB actuator bridge: the ROS host owns all kinematics and
// calibration; this firmware only moves servos to commanded pulses and reports
// the pulses it reads back. This is the "direct servo driver" path.
//
// Contract with the host:
//   sub  /arm/servo_command  std_msgs/Float32MultiArray  data=[p1, p2, p3, time_ms]
//        p1,p2,p3 = Lobot pulses (0..1000) for servos 1,2,3; time_ms = move duration.
//   pub  /arm/servo_feedback std_msgs/Float32MultiArray  data=[p1, p2, p3]
//        pulses read back from servos 1,2,3, published at ~FEEDBACK_HZ.
//
// Safety: pulses are clamped to [0,1000] AND to the company's mechanical guards
// (servo2 <= 700, servo3 >= 470) so we never drive the linkage into itself.
//
// Build: place this .ino with the company's LobotSerialServoControl.{h,cpp} in the
// same sketch folder (copy them from ../../kinematics_move/). Requires the
// micro_ros_arduino library. Original kinematics_move.ino is left untouched.

#include <micro_ros_arduino.h>
#include <rcl/rcl.h>
#include <rclc/rclc.h>
#include <rclc/executor.h>
#include <std_msgs/msg/float32_multi_array.h>

#include "LobotSerialServoControl.h"

// ---- servo bus wiring (matches the company ESPMax.cpp) ----
#define SERVO_SERIAL_RX 35
#define SERVO_SERIAL_TX 12
// Half-duplex bus direction-enable pins. The company ESPMax.cpp #defines these
// (receiveEnablePin 13, transmitEnablePin 14) but constructs BusServo with the
// single-arg (auto-direction) constructor, so they are never driven -- which is
// why writes work (TX defaults enabled) but reads return nothing (RX never
// enabled). Passing them to the 3-arg constructor makes the library flip
// direction (TxEnable before write, RxEnable before read) so feedback works.
#define SERVO_RX_ENABLE 13
#define SERVO_TX_ENABLE 14
HardwareSerial ServoSerial(2);
LobotSerialServoControl BusServo(ServoSerial, SERVO_RX_ENABLE, SERVO_TX_ENABLE);

// ---- behaviour ----
#define NUM_SERVOS   3
#define FEEDBACK_HZ  20
#define DEFAULT_TIME 1000   // ms, used if the host omits a move time

// ---- micro-ROS handles ----
rcl_subscription_t sub_cmd;
rcl_publisher_t    pub_fb;
std_msgs__msg__Float32MultiArray msg_cmd;
std_msgs__msg__Float32MultiArray msg_fb;
rclc_executor_t executor;
rclc_support_t  support;
rcl_allocator_t allocator;
rcl_node_t      node;
rcl_timer_t     fb_timer;

// static backing storage for the Float32MultiArray payloads (micro-ROS needs the
// sequence buffers pre-allocated; no dynamic allocation at runtime).
static float cmd_buf[4];   // [p1, p2, p3, time_ms]
static float fb_buf[NUM_SERVOS];

static inline float clampf(float v, float lo, float hi) {
    return v < lo ? lo : (v > hi ? hi : v);
}

// Clamp a pulse to [0,1000] and apply the company's per-servo mechanical guards.
static int safe_pulse(int servo_id, float pulse) {
    int p = (int)(pulse + 0.5f);
    p = (int)clampf((float)p, 0.0f, 1000.0f);
    if (servo_id == 2 && p > 700) p = 700;   // shoulder upper guard
    if (servo_id == 3 && p < 470) p = 470;   // elbow lower guard
    return p;
}

// Called when the host sends a new servo command.
void command_callback(const void * msgin) {
    const std_msgs__msg__Float32MultiArray * m =
        (const std_msgs__msg__Float32MultiArray *)msgin;
    if (m->data.size < NUM_SERVOS) return;   // ignore malformed commands

    uint16_t move_time = DEFAULT_TIME;
    if (m->data.size >= 4 && m->data.data[3] > 0.0f) {
        move_time = (uint16_t)clampf(m->data.data[3], 20.0f, 30000.0f);
    }
    for (int i = 0; i < NUM_SERVOS; i++) {
        int p = safe_pulse(i + 1, m->data.data[i]);
        BusServo.LobotSerialServoMove(i + 1, p, move_time);
        delay(2);   // small gap between bus writes, as in the company code
    }
}

// Publish read-back pulses on a fixed timer.
void feedback_timer_callback(rcl_timer_t * timer, int64_t last_call_time) {
    (void)last_call_time;
    if (timer == NULL) return;
    for (int i = 0; i < NUM_SERVOS; i++) {
        int p = BusServo.LobotSerialServoReadPosition(i + 1);
        fb_buf[i] = (float)p;   // negative => read error; host can detect/ignore
    }
    msg_fb.data.size = NUM_SERVOS;
    rcl_publish(&pub_fb, &msg_fb, NULL);
}

void setup() {
    set_microros_transports();
    delay(2000);

    BusServo.OnInit();
    ServoSerial.begin(115200, SERIAL_8N1, SERVO_SERIAL_RX, SERVO_SERIAL_TX);

    allocator = rcl_get_default_allocator();
    rclc_support_init(&support, 0, NULL, &allocator);
    rclc_node_init_default(&node, "espmax_joint_node", "", &support);

    // bind the static buffers to the message sequences
    msg_cmd.data.data     = cmd_buf;
    msg_cmd.data.capacity = 4;
    msg_cmd.data.size     = 0;
    msg_fb.data.data      = fb_buf;
    msg_fb.data.capacity  = NUM_SERVOS;
    msg_fb.data.size      = NUM_SERVOS;

    rclc_subscription_init_default(
        &sub_cmd, &node,
        ROSIDL_GET_MSG_TYPE_SUPPORT(std_msgs, msg, Float32MultiArray),
        "/arm/servo_command");

    rclc_publisher_init_default(
        &pub_fb, &node,
        ROSIDL_GET_MSG_TYPE_SUPPORT(std_msgs, msg, Float32MultiArray),
        "/arm/servo_feedback");

    rclc_timer_init_default(
        &fb_timer, &support, RCL_MS_TO_NS(1000 / FEEDBACK_HZ),
        feedback_timer_callback);

    rclc_executor_init(&executor, &support.context, 2, &allocator);
    rclc_executor_add_subscription(&executor, &sub_cmd, &msg_cmd,
        &command_callback, ON_NEW_DATA);
    rclc_executor_add_timer(&executor, &fb_timer);
}

void loop() {
    rclc_executor_spin_some(&executor, RCL_MS_TO_NS(20));
}

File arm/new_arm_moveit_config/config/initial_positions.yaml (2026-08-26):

# Starting joint values for the mock hardware at launch (all at home).
initial_positions:
  after_base_full_joint: 0.0
  link1_joint: 0.0
  link2_joint: 0.0
  end_effector_joint: 0.0

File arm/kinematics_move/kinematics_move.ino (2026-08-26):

#include <micro_ros_arduino.h>
#include <rcl/rcl.h>
#include <rclc/rclc.h>
#include <rclc/executor.h>
#include <geometry_msgs/msg/point.h>

#include "ESPMax.h"
#include "_espmax.h"
#include "Buzzer.h"

// micro-ROS handles
rcl_subscription_t subscriber;
geometry_msgs__msg__Point msg;
rclc_executor_t executor;
rclc_support_t support;
rcl_allocator_t allocator;
rcl_node_t node;

float pos[3];
bool new_msg = false;

bool inRange(float x, float y, float z) {
    if (x < -291.34 || x > 291.34) return false;
    if (y < -291.34 || y > 291.34) return false;
    if (z < -182.0  || z > 350.8)  return false;
    return true;
}

// Called every time a message arrives on /arm_position
void subscription_callback(const void * msgin) {
    const geometry_msgs__msg__Point * msg = (const geometry_msgs__msg__Point *)msgin;
    pos[0] = msg->x;
    pos[1] = msg->y;
    pos[2] = msg->z;
    new_msg = true;
}

void setup() {
    set_microros_transports();
    delay(2000);

    Buzzer_init();
    ESPMax_init();
    go_home(2000);
    delay(2000);

    allocator = rcl_get_default_allocator();
    rclc_support_init(&support, 0, NULL, &allocator);
    rclc_node_init_default(&node, "espmax_node", "", &support);

    rclc_subscription_init_default(
        &subscriber, &node,
        ROSIDL_GET_MSG_TYPE_SUPPORT(geometry_msgs, msg, Point),
        "/arm_position"
    );

    rclc_executor_init(&executor, &support.context, 1, &allocator);
    rclc_executor_add_subscription(&executor, &subscriber, &msg,
        &subscription_callback, ON_NEW_DATA);
}

void loop() {
    rclc_executor_spin_some(&executor, RCL_MS_TO_NS(100));

    if (new_msg) {
        new_msg = false;

        if (!inRange(pos[0], pos[1], pos[2])) {
            // out of range — ignore silently or beepError()
            return;
        }

        set_position(pos, 2000);
        delay(2000);
    }
}

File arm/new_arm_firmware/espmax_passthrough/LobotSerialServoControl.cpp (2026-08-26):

//
//* FileName:      LobotSerialServoControl.h
//* Company:     Hiwonder
//* Date:          2020/05/13  16:53
// *Last Modification Date: 202005131938
//* www.hiwonder.com

#include "LobotSerialServoControl.h"
#include <Stream.h>

LobotSerialServoControl::LobotSerialServoControl(HardwareSerial &A)
{
  isAutoEnableRT = true;
	isUseHardwareSerial = true;
	SerialX = (Stream*)(&A);
}
LobotSerialServoControl::LobotSerialServoControl(HardwareSerial &A,int receiveEnablePin, int transmitEnablePin)
{
  isAutoEnableRT = false;
  this->receiveEnablePin = receiveEnablePin;
  this->transmitEnablePin = transmitEnablePin;
  
  isUseHardwareSerial = true;
  SerialX = (Stream*)(&A);
}

void LobotSerialServoControl::OnInit(void)
{
  if(!isAutoEnableRT)
  {
    pinMode(receiveEnablePin, OUTPUT);
    pinMode(transmitEnablePin, OUTPUT);
    RxEnable();
  }
}

inline void LobotSerialServoControl::RxEnable(void)
{
  digitalWrite(receiveEnablePin, HIGH);
  digitalWrite(transmitEnablePin, LOW);
}
inline void LobotSerialServoControl::TxEnable(void)
{
  digitalWrite(receiveEnablePin, LOW);
  digitalWrite(transmitEnablePin, HIGH);
}

byte LobotSerialServoControl::LobotCheckSum(byte buf[])
{
  byte i;
  uint16_t temp = 0;
  for (i = 2; i < buf[3] + 2; i++) {
    temp += buf[i];
  }
  temp = ~temp;
  i = (byte)temp;
  return i;
}

void LobotSerialServoControl::LobotSerialServoMove(uint8_t id, int16_t position, uint16_t time)
{
  byte buf[10];
  if(position < 0)
    position = 0;
  if(position > 1000)
    position = 1000;
  buf[0] = buf[1] = LOBOT_SERVO_FRAME_HEADER;
  buf[2] = id;
  buf[3] = 7;
  buf[4] = LOBOT_SERVO_MOVE_TIME_WRITE;
  buf[5] = GET_LOW_BYTE(position);
  buf[6] = GET_HIGH_BYTE(position);
  buf[7] = GET_LOW_BYTE(time);
  buf[8] = GET_HIGH_BYTE(time);
  buf[9] = LobotCheckSum(buf);
  if(isAutoEnableRT == false)
    TxEnable();
  SerialX->write(buf, 10);
}

void LobotSerialServoControl::LobotSerialServoStopMove(uint8_t id)
{
  byte buf[6];
  buf[0] = buf[1] = LOBOT_SERVO_FRAME_HEADER;
  buf[2] = id;
  buf[3] = 3;
  buf[4] = LOBOT_SERVO_MOVE_STOP;
  buf[5] = LobotCheckSum(buf);
  if(isAutoEnableRT == false)
    TxEnable();
  SerialX->write(buf, 6);
}

void LobotSerialServoControl::LobotSerialServoSetID(uint8_t oldID, uint8_t newID)
{
  byte buf[7];
  buf[0] = buf[1] = LOBOT_SERVO_FRAME_HEADER;
  buf[2] = oldID;
  buf[3] = 4;
  buf[4] = LOBOT_SERVO_ID_WRITE;
  buf[5] = newID;
  buf[6] = LobotCheckSum(buf);
  if(isAutoEnableRT == false)
    TxEnable();
  SerialX->write(buf, 7);
  
#ifdef LOBOT_DEBUG
  Serial.println("LOBOT SERVO ID WRITE");
  int debug_value_i = 0;
  for (debug_value_i = 0; debug_value_i < buf[3] + 3; debug_value_i++)
  {
    Serial.print(buf[debug_value_i], HEX);
    Serial.print(":");
  }
  Serial.println(" ");
#endif

}

void LobotSerialServoControl::LobotSerialServoSetMode(uint8_t id, uint8_t Mode, int16_t Speed)
{
  byte buf[10];

  buf[0] = buf[1] = LOBOT_SERVO_FRAME_HEADER;
  buf[2] = id;
  buf[3] = 7;
  buf[4] = LOBOT_SERVO_OR_MOTOR_MODE_WRITE;
  buf[5] = Mode;
  buf[6] = 0;
  buf[7] = GET_LOW_BYTE((uint16_t)Speed);
  buf[8] = GET_HIGH_BYTE((uint16_t)Speed);
  buf[9] = LobotCheckSum(buf);

#ifdef LOBOT_DEBUG
  Serial.println("LOBOT SERVO Set Mode");
  int debug_value_i = 0;
  for (debug_value_i = 0; debug_value_i < buf[3] + 3; debug_value_i++)
  {
    Serial.print(buf[debug_value_i], HEX);
    Serial.print(":");
  }
  Serial.println(" ");
#endif
  if(isAutoEnableRT == false)
    TxEnable();
  SerialX->write(buf, 10);
}

void LobotSerialServoControl::LobotSerialServoLoad(uint8_t id)
{
  byte buf[7];
  buf[0] = buf[1] = LOBOT_SERVO_FRAME_HEADER;
  buf[2] = id;
  buf[3] = 4;
  buf[4] = LOBOT_SERVO_LOAD_OR_UNLOAD_WRITE;
  buf[5] = 1;
  buf[6] = LobotCheckSum(buf);
  if(isAutoEnableRT == false)
    TxEnable();
  SerialX->write(buf, 7);
  
#ifdef LOBOT_DEBUG
  Serial.println("LOBOT SERVO LOAD WRITE");
  int debug_value_i = 0;
  for (debug_value_i = 0; debug_value_i < buf[3] + 3; debug_value_i++)
  {
    Serial.print(buf[debug_value_i], HEX);
    Serial.print(":");
  }
  Serial.println(" ");
#endif

}

void LobotSerialServoControl::LobotSerialServoUnload(uint8_t id)
{
  byte buf[7];
  buf[0] = buf[1] = LOBOT_SERVO_FRAME_HEADER;
  buf[2] = id;
  buf[3] = 4;
  buf[4] = LOBOT_SERVO_LOAD_OR_UNLOAD_WRITE;
  buf[5] = 0;
  buf[6] = LobotCheckSum(buf);
  if(isAutoEnableRT == false)
    TxEnable();
  SerialX->write(buf, 7);
  
#ifdef LOBOT_DEBUG
  Serial.println("LOBOT SERVO LOAD WRITE");
  int debug_value_i = 0;
  for (debug_value_i = 0; debug_value_i < buf[3] + 3; debug_value_i++)
  {
    Serial.print(buf[debug_value_i], HEX);
    Serial.print(":");
  }
  Serial.println(" ");
#endif
}

int LobotSerialServoControl::LobotSerialServoReceiveHandle(byte *ret)
{
  bool frameStarted = false;
  bool receiveFinished = false;
  byte frameCount = 0;
  byte dataCount = 0;
  byte dataLength = 2;
  byte rxBuf;
  byte recvBuf[32];
  byte i;

  int _guard = 80;   // cap bytes processed: prevents an infinite loop (and a hung
                     // feedback timer) if the half-duplex line streams noise.
  while (SerialX->available() && _guard-- > 0) {
    rxBuf = SerialX->read();
    delayMicroseconds(100);
    if (!frameStarted) {
      if (rxBuf == LOBOT_SERVO_FRAME_HEADER) {
        frameCount++;
        if (frameCount == 2) {
          frameCount = 0;
          frameStarted = true;
          dataCount = 1;
        }
      }
      else {
        frameStarted = false;
        dataCount = 0;
        frameCount = 0;
      }
    }
    if (frameStarted) {
      recvBuf[dataCount] = (uint8_t)rxBuf;
      if (dataCount == 3) {
        dataLength = recvBuf[dataCount];
        if (dataLength < 3 || dataCount > 7) {
          dataLength = 2;
          frameStarted = false;
        }
      }
      dataCount++;
      if (dataCount == dataLength + 3) {
        
#ifdef LOBOT_DEBUG
        Serial.print("RECEIVE DATA:");
        for (i = 0; i < dataCount; i++) {
          Serial.print(recvBuf[i], HEX);
          Serial.print(":");
        }
        Serial.println(" ");
#endif

        if (LobotCheckSum(recvBuf) == recvBuf[dataCount - 1]) {
          
#ifdef LOBOT_DEBUG
          Serial.println("Check SUM OK!!");
          Serial.println("");
#endif

          frameStarted = false;
          memcpy(ret, recvBuf + 4, dataLength);
          return 1;
        }
        return -1;
      }
    }
  }
  return -1;   // no complete/valid frame received (stock code fell off the end here)
}

int LobotSerialServoControl::LobotSerialServoReadPosition(uint8_t id)
{
  int ret;
  byte buf[6];

  buf[0] = buf[1] = LOBOT_SERVO_FRAME_HEADER;
  buf[2] = id;
  buf[3] = 3;
  buf[4] = LOBOT_SERVO_POS_READ;
  buf[5] = LobotCheckSum(buf);
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

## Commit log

2026-06-17 Add arm subsystem (stage 1 of the mobile manipulator)
    First stage of the dynamic-visual-SLAM mobile manipulator: the complete 4-DOF
    arm. The mobile base and the integrated arm-on-base system will be added later
    as separate top-level directories, so the arm lives under arm/.
    Packages (arm/):
    - New_arm, new_arm_description CAD/URDF model + STL meshes (RViz display)
    - new_arm_ik analytic 3-DOF IK + GUI node + kinematics derivation
    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
    [New_arm.urdf, after base full.stl, after_base_full.stl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]
2026-06-17 Add Isaac Sim ROS2 driver, publishers, and diagnostics tooling
    - robot_drive_and_publish.py: drive the mobile base (arrow-key GUI + /cmd_vel)
    and publish color/depth/points, joint_states, tf, odom, clock. Adds
    --robot-prefix for payloaded scenes (lizard.usd), forces GPU dynamics so the
    SDF wheel colliders actually collide, TorqueNADO DC-motor model, startup-lurch
    suppression, and timeline auto-resume.
    - robot_base_camera_ros.py: camera-only publisher.
    - Tuning/build: apply_motor_model, apply_scene_fixes, rescale_sdf, rescale_robot,
    make_gui_copy, build_4wd, build_ball_caster.
    - Diagnostics: diagnose_motion, kinematics_probe, geom_inspect, direction_check,
    depth_probe, motor_test,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
2026-06-17 Add mobile-robot USD scenes and diagnostic renders
    - lizard.usd: scaled 4-inch robot (payloads new_built_robot_ros.usd).
    - new_built_robot.usd plus _ros/_gui copies and the pre-rescale backup: 2WD
    differential-drive base + welded D435i + ground/obstacles.
    - Older scene experiments and the render PNGs from render_robot.py.
    - Arm assets (arm_with_all_links.usd, robo_oral_with_arm.usd) and the 11 MB
    robotna.usdz are intentionally excluded via .gitignore: the arm work is
    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
2026-08-26 Add SLAM evaluation figures, robot specs, and driver improvements
    - robot_drive_and_publish.py: expanded Isaac Sim ROS2 driver (+465 lines)
    - ROBOT_SPECS.md: measured mass, dimensions, COM, and wheel specs for the
    4-inch differential-drive base with welded D435i
    - make_figures.py / plot_slam_path.py / query_specs.py: figure and specs
    generation tooling
    - figures/: report figures for SLAM accuracy, socket detection, and
    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
    [traj.csv]
2026-08-26 Rewrite README around the graduation report; add photos, demo, and PDF
    Replaces the arm-only README with one covering the full EV-charging system.
    Results are taken verbatim from the report's tables (SLAM ATE/RPE, socket pose
    vs. lighting, approach navigation, DR ablation) and each is labelled with where
    it was validated.
    The report's own Table 16 and conclusion state that dynamic masking, nvblox,
    Nav2, and the PPO policy are Isaac Sim only, and that the 30-trial physical
    insertion set and end-to-end mission have not been run. The README mirrors that
    rather than presenting simulation figures as hardware performance.
    - docs/GRADUATION_REPORT.pdf: 69-page report, Ghostscript /ebook (31 MB ->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
2026-08-26 Correct RL insertion accuracy to 96.2%
    The report's Table 14 records ~94.5% as a development observation; 96.2% (best
    checkpoint) is the correct figure and matches the arm task table below it.
2026-08-26 Repair warehouse.usd prop references; add robot scene render
    env/warehouse.usd was committed as an empty shell. All 424 of its prop references
    pointed at a local ./Props/ (and ../../Props/) directory that was never copied
    alongside it, so the file composed to 447 prims and exactly ONE mesh -- transforms
    positioning geometry that did not exist.
    Re-pointed every reference at NVIDIA's Isaac 5.1 asset server, respecting the two
    distinct path families: ./Props/ resolves under Environments/Simple_Warehouse/
    (286 refs) while ../../Props/ resolves under Isaac/Props/ (138 refs). Verified by
    opening all three variants in Isaac Sim:
    original 447 prims, 1 mesh
    partial fix 1914 prims, 367 m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
